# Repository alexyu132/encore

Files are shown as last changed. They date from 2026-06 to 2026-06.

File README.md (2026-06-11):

# encore
A mini CoreXY 3D printer with a 3D printed frame.

printer header imaeg

Overview video: https://www.youtube.com/watch?v=9xukniyO6fI

This is my latest CoreXY design. It's a small printer with a 120x120x120mm build volume. The total size is slightly smaller than a Voron 0, with a footprint approximately the size of a box of filament.

Unlike my older printer designs, this one uniquely uses an entirely 3D printed chassis, with no aluminum extrusions or custom CNC'd parts. This significantly reduces the total part cost, while the solid panel construction keeps things sufficiently rigid.

All of the printed parts are designed to fit on a 225mm bed, so common printers like the Ender 3, Bambu A1/P1, etc. should have no problem printing them.

For this design I focused on keeping things compact yet modular. Each major assembly (e.g. the CoreXY mechanism, the Z axis, and the outer panels, can be independently swapped out without major disassembly of the other assemblies.

| Specs |  |
| --- | --- |
| Build volume | ~120x120x120mm |
| Body dimensions (excl. Bowden parts)| 219x221x262mm|
| Extrusion| Bambu-style hotend, Bowden extruder|
| Motion| MGN9C X/Y gantry, 8mm linear rod Z + 8mm leadscrew|
| Cooling| 4015 blower (print head) + dual 7515 blower (aux)|

# BOM and assembly
View the list of printed and non-printed parts [here](documentation/BOM.md).

Assembly guide is available [here](documentation/build%20guide/build%20guide.md). Note: still WIP

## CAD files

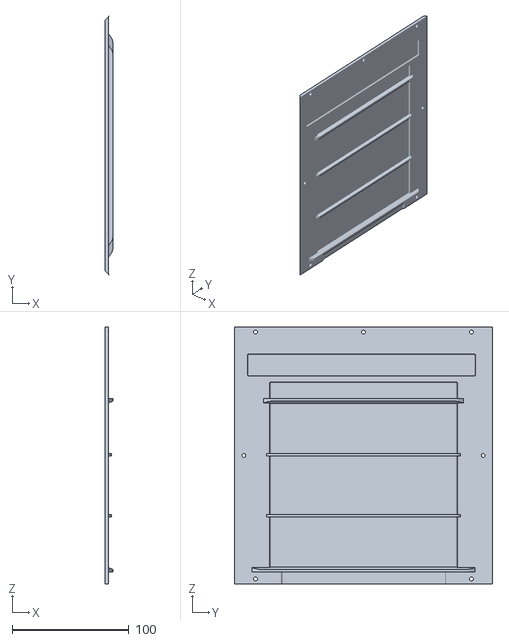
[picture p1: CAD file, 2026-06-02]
stl/enclosure/left panel unvented.stl
6.50 x 221.0 x 220.0

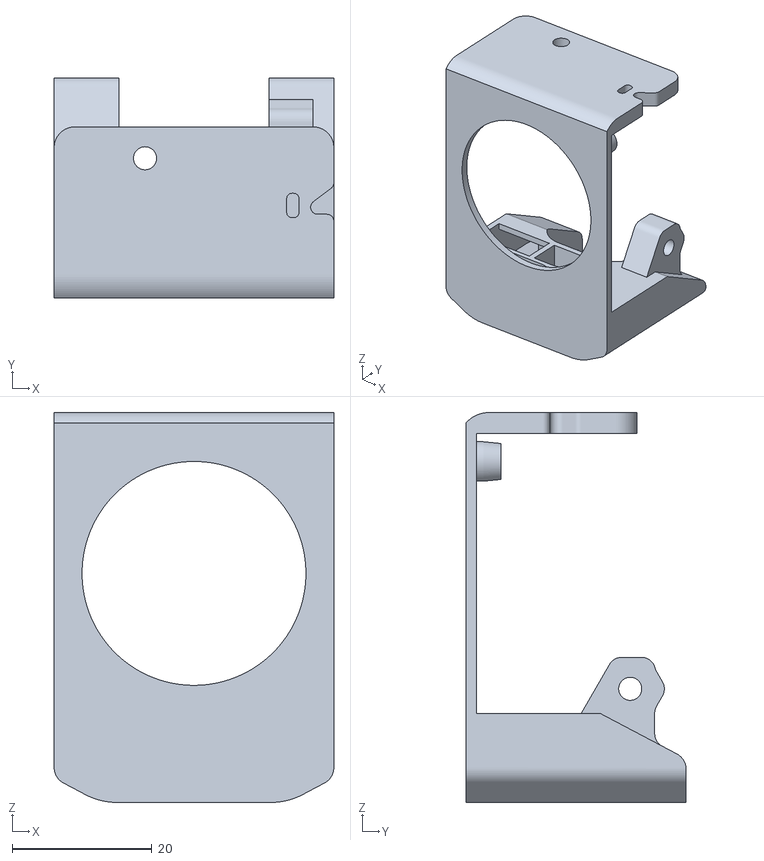
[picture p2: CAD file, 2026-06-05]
stl/gantry/print head/print fan duct.stl
40.0 x 31.5 x 55.8

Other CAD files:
stl/enclosure/right panel unvented.stl

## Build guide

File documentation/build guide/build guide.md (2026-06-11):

# Encore build guide

WIP: This is a very early version. Please flag any discrepancies via Github Issues.

## Contents

### 0. [(Pre-build) BOM](../BOM.md)

### 1. [Gantry](gantry.md)

### 2. Enclosure and Z axis

### 3. Final assembly and wiring

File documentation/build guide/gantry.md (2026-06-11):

# Encore build guide: Gantry

## 1. Front idler block pulleys

### Printed parts:
|Item|Qty|
|--|--|
|Left front idler block|1|
|Right front idler block|1|

### Non-printed parts:
|Item|Qty|
|--|--|
|M3x20mm bolt |2|
|M3 lock nut|2|
| F623 bearing |4|

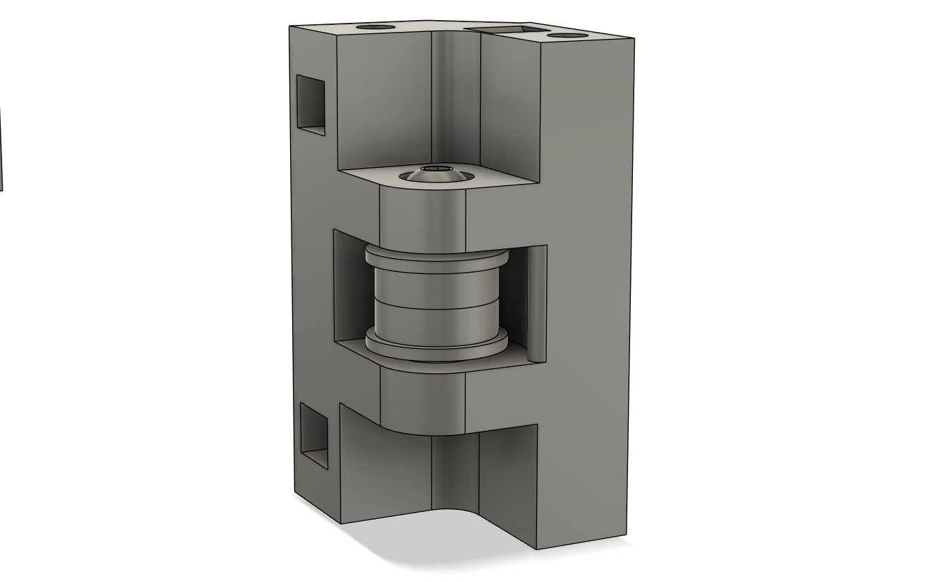
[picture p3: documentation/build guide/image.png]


For each front idler block:
- Insert 2 F623 bearings into the pulley slot. The flanges should be facing away from each other.
- Secure with an M3x20mm bolt and lock nut underneath.

## 2. Rear idler blocks and mid frame

### Printed parts:
|Item|Qty|
|--|--|
| Rear idler spacer |2|
| Rear left idler block |1|
| Rear right idler block |1|
| Rear mid frame | 1|

### Non-printed parts:
|Item|Qty|
|--|--|
|M3x30mm bolt | 4|
|M3 lock nut| 4|
|F623 bearing| 12|

For each rear idler block, install pulleys as shown in the image below. Use M3x30mm bolts inserted from the top of the part. For the double stacked pulley, the order is:
1. F623 (flange on top)
2. F623 (flange on bottom)
3. Rear idler spacer
4. F623 (flange on top)
5. F623 (flange on bottom)

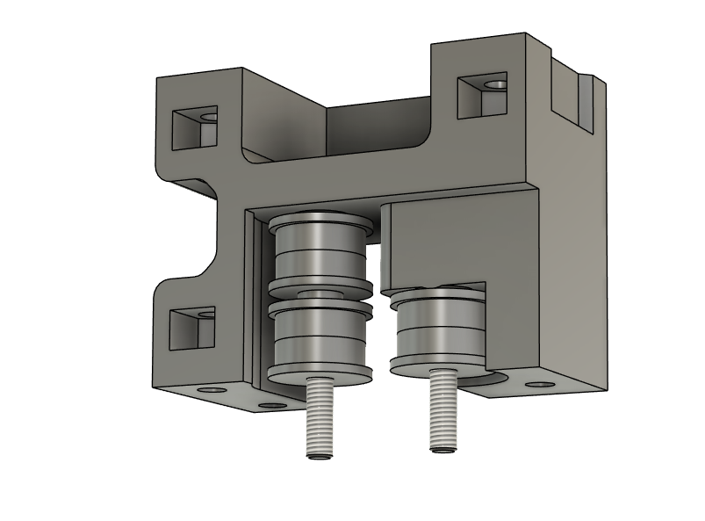
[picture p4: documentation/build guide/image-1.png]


Install the rear midframe underneath and secure the M3x30mm bolts via 2 M3 lock nuts.
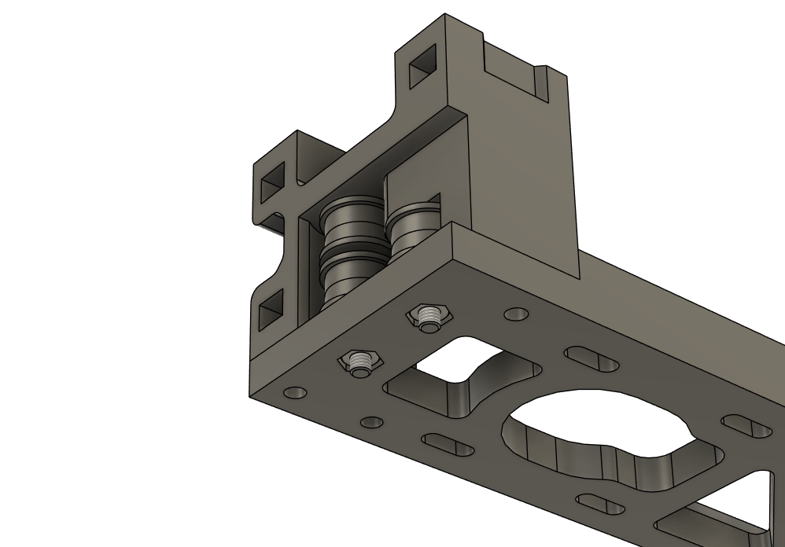
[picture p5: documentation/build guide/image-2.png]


Repeat the same steps for the other side; the resulting assembly should look like the following:
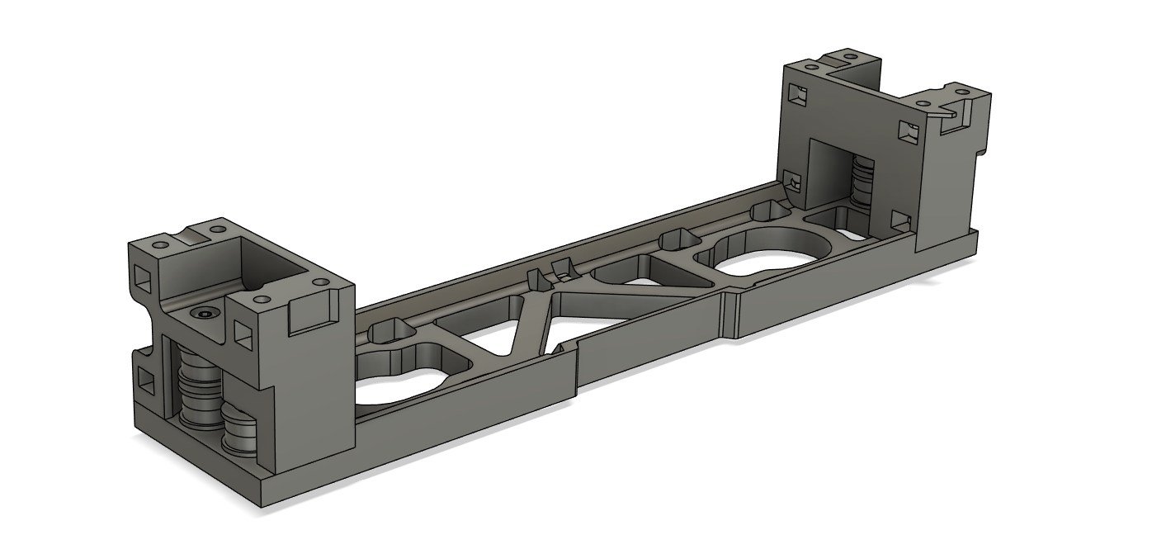
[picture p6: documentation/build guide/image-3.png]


## 3. Upper frame attachment

### Printed parts:
|Item|Qty|
|--|--|
| Top chassis |1|

### Non-printed parts:
|Item|Qty|
|--|--|
|M3x12mm bolt | 12|
|M3 lock nut| 12|

Insert 4 lock nuts into the top slots of the rear left and right idler blocks
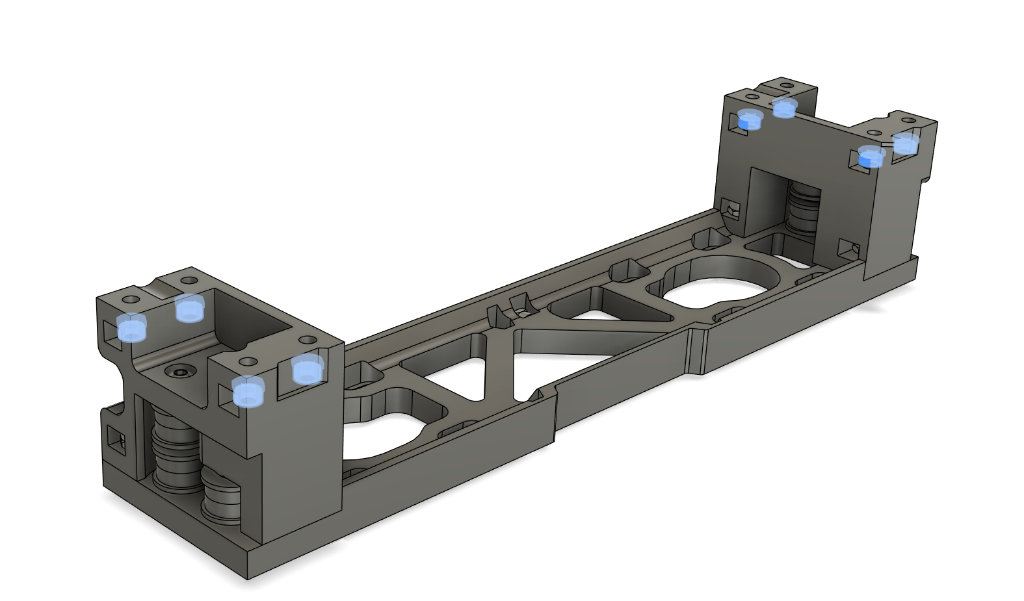
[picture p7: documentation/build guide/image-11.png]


Attach the top chassis to the rear idler assembly using 8 M3x12mm bolts:
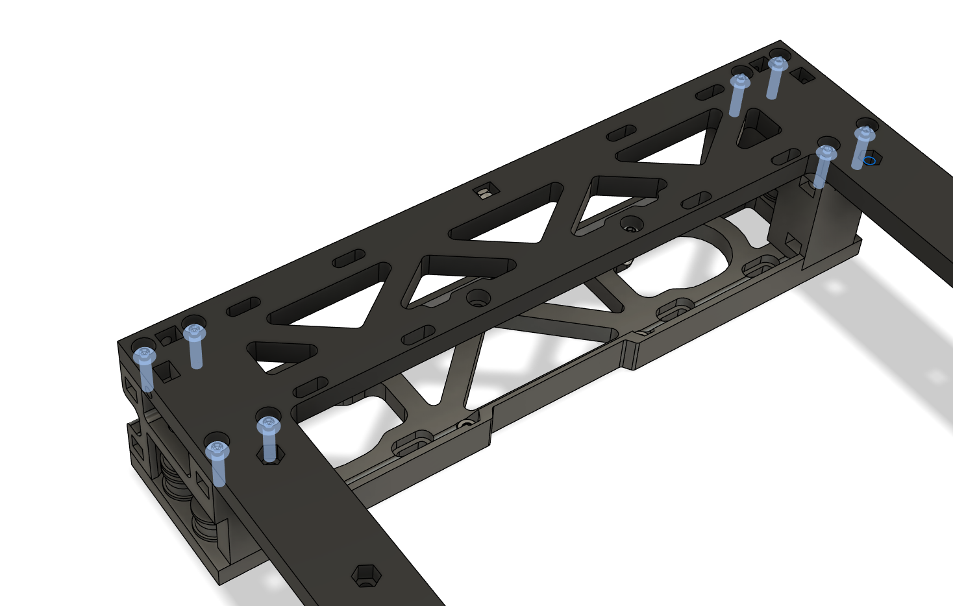
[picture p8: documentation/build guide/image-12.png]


Attach the left/right front idler blocks to the top chassis using 4 M3x12mm bolts and 4 lock nuts:
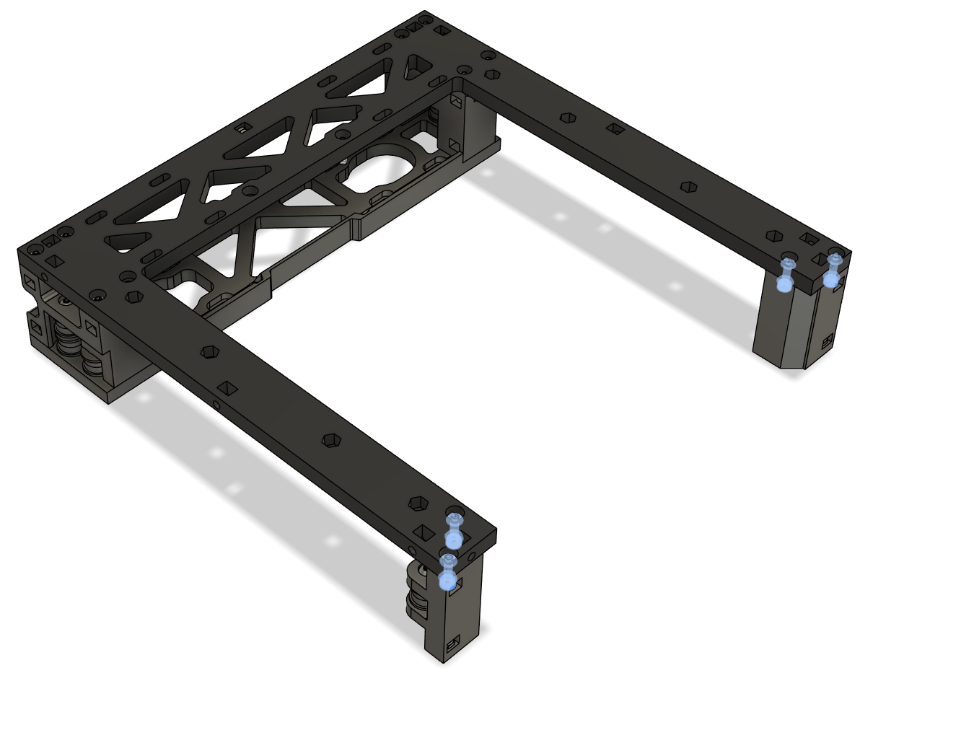
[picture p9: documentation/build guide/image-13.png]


## 4. Linear rail installation

### Non-printed parts:
|Item|Qty|
|--|--|
| 150mm MGN9 rail with MGN9C carriage |2|
|M3x10mm bolt | 8|
|M3 lock nut| 8|

Note: The linear rails should be properly prepped and greased before assembly. See this guide for the necessary steps: https://docs.ldomotors.com/guides/rail_grease_guide

Install the right side linear rail using 4 M3x10mm bolts and 4 lock nuts. Note: use the triangular tabs on the front/rear right idler blocks to align the rail.
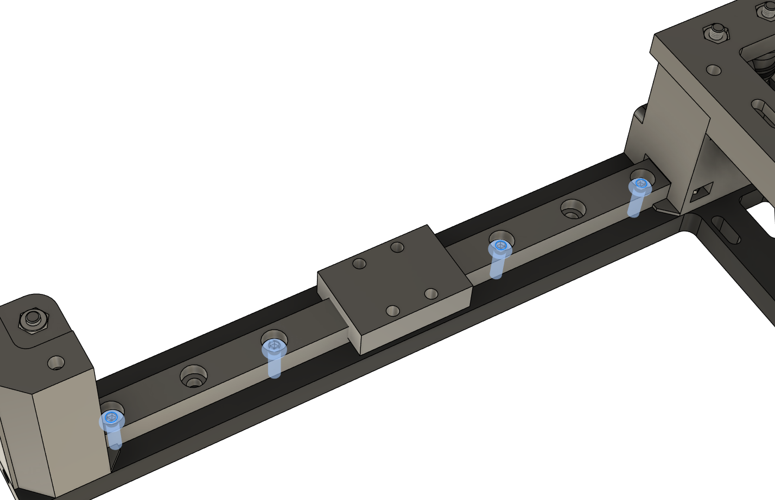
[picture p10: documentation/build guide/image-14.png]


Install the left side linear rail in the same fashion. NOTE: Leave the bolts loose for now; final tightening will be done when the X gantry is installed.
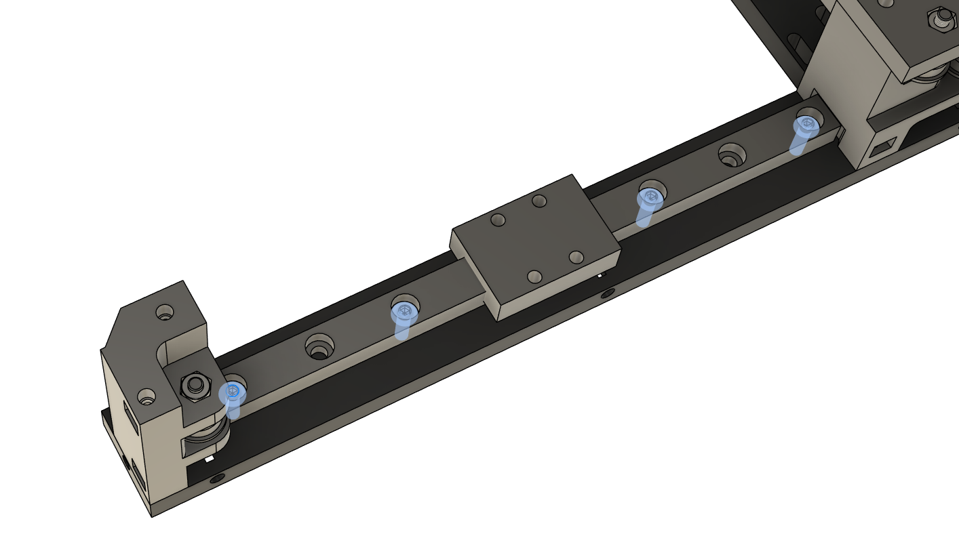
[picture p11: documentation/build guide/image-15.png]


## 5. X gantry assembly
### Printed parts:
|Item|Qty|
|--|--|
| Gantry body |1|
| Gantry left end |1|
| Gantry right end |1|

### Non-printed parts:
|Item|Qty|
|--|--|
|M3x25mm bolt | 4|
|M3x12mm bolt | 4|
|M3x30mm bolt |4|
|M3 lock nut| 8|
| 150mm MGN9 rail with MGN9C carriage | 1 |

Install 2 M3x25mm bolts and F623 bearings as shown onto the gantry left end:

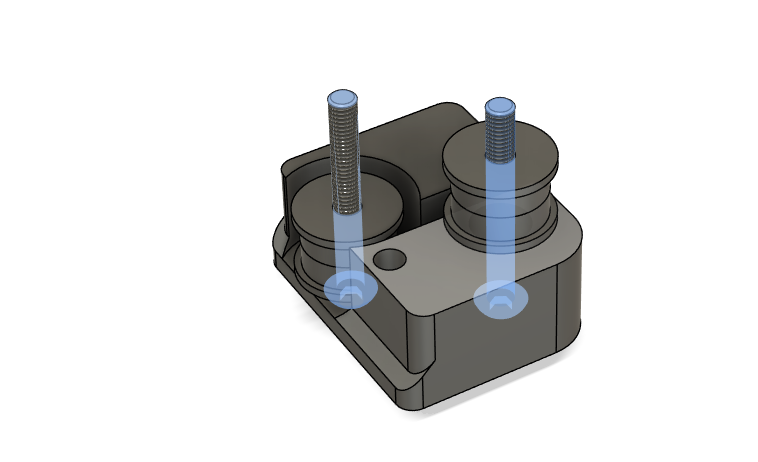
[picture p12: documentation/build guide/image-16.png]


Secure the left end onto the gantry body using 2 lock nuts:
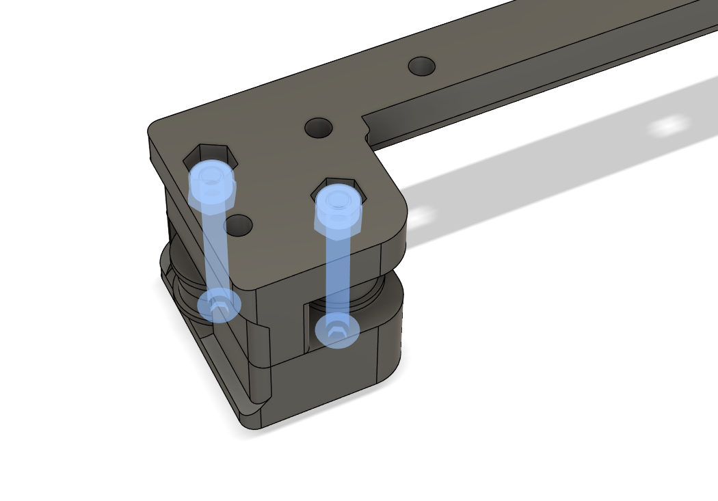
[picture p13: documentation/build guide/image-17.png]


Repeat the same steps for the right end:
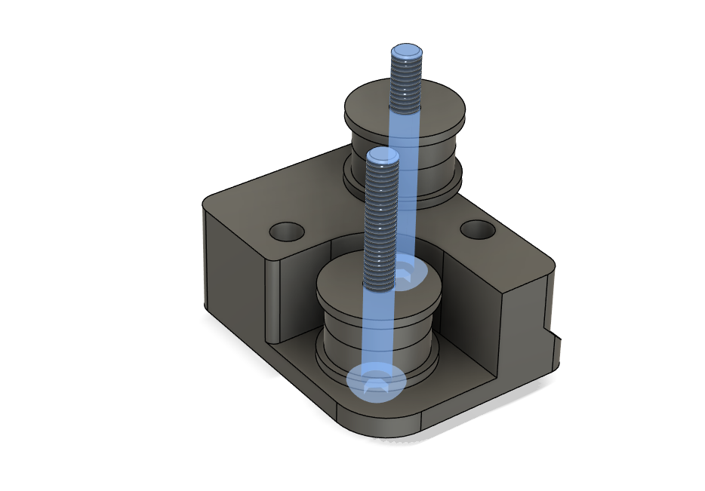
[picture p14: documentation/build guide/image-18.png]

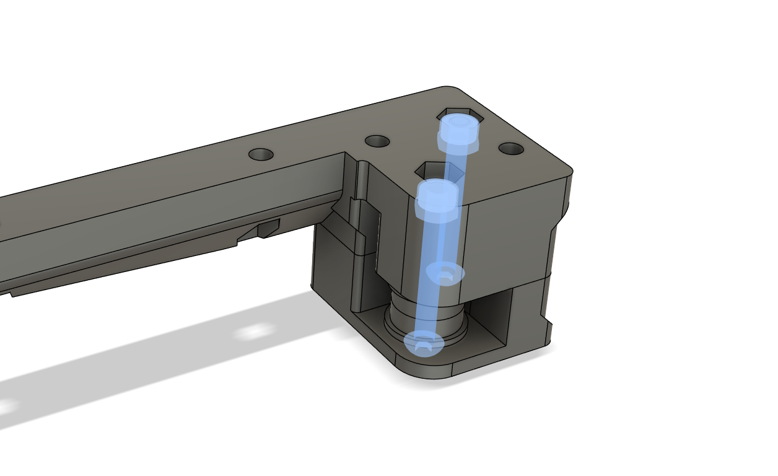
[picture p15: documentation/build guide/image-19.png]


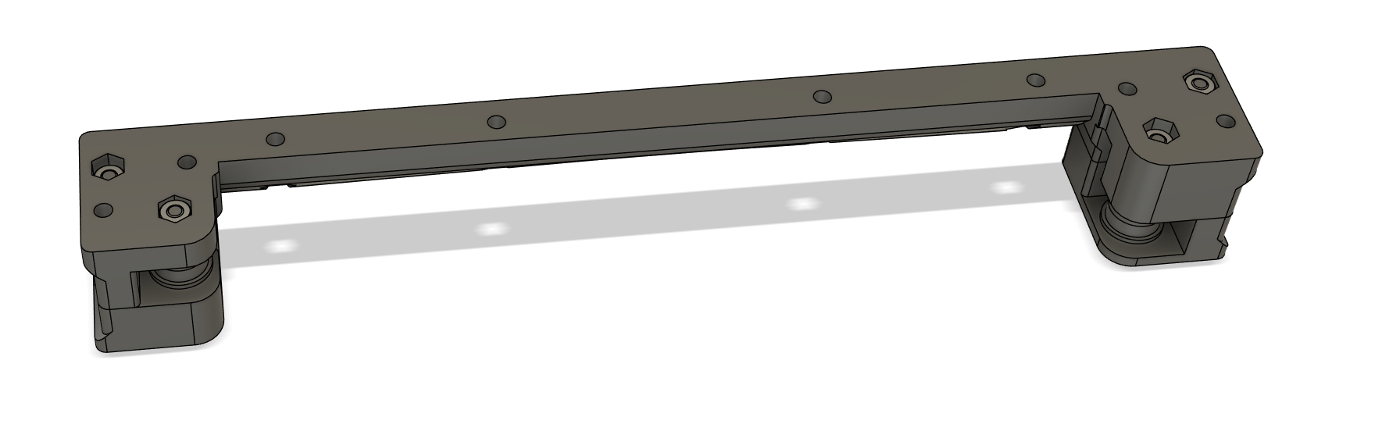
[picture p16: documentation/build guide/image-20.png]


Use 4 M3x12mm bolts and 4 lock nuts to secure the 150mm MGN9 rail to the gantry body:
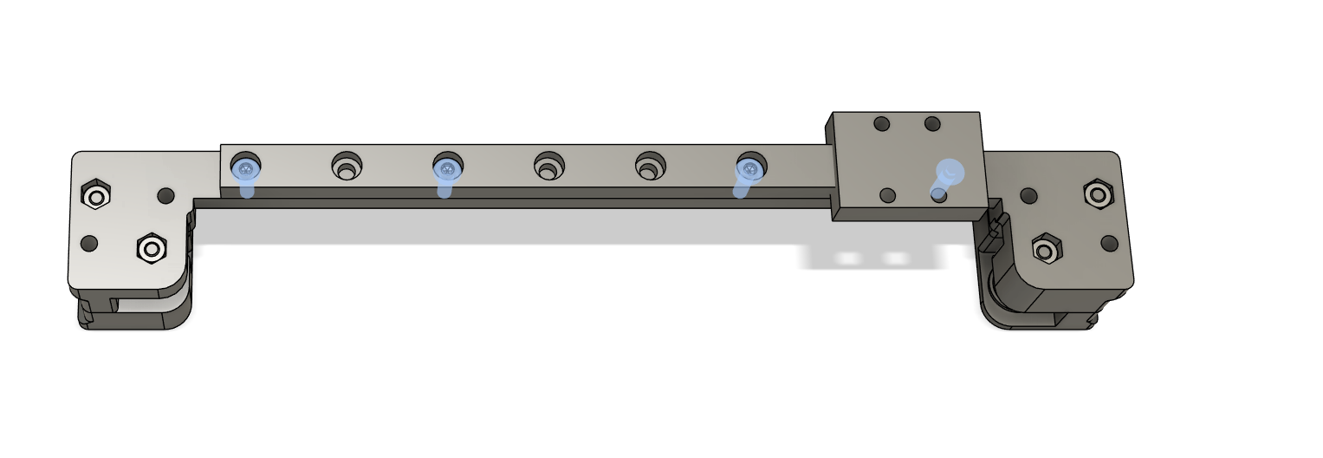
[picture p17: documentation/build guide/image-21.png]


Use 4 M3x30mm bolts to secure the X gantry to the Y rails:
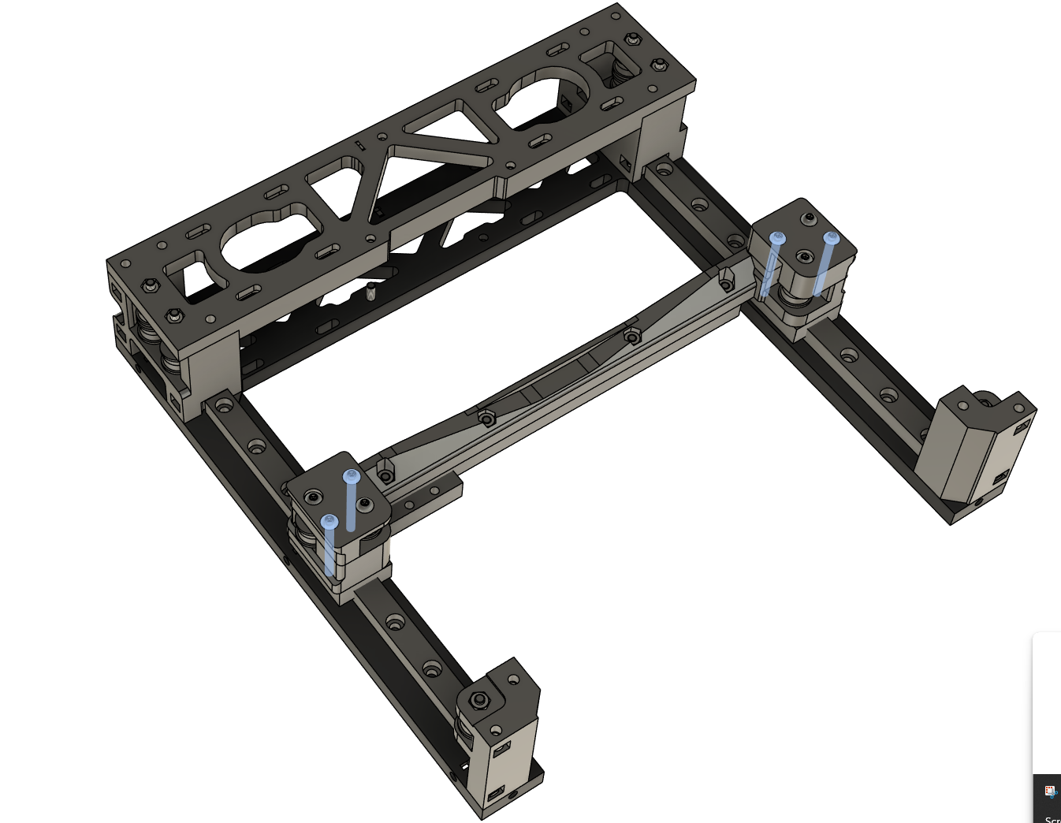
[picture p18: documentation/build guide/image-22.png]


After the X gantry is installed, run it back and forth to each end, and tighten the bolts on the left Y rail. Make sure movement is smooth throughout the entire Y travel.
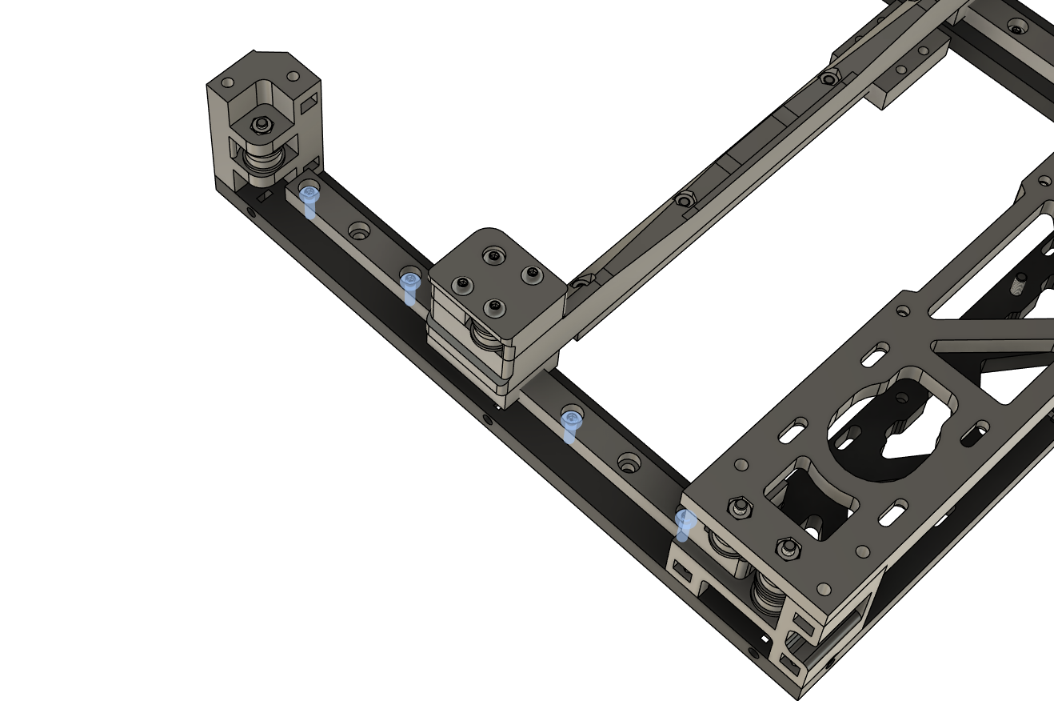
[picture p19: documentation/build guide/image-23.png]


## 6. Y endstop installation

### Printed parts:
|Item|Qty|
|--|--|
| Y endstop mount |1|

### Non-printed parts:
|Item|Qty|
|--|--|
|M3x8mm bolt | 2|
|M3x10mm bolt |2|
|M3 lock nut| 4|
| PCB endstop | 1 |

Install a PCB endstop onto the Y endstop mount using 2 M3x8mm bolts and 2 lock nuts:
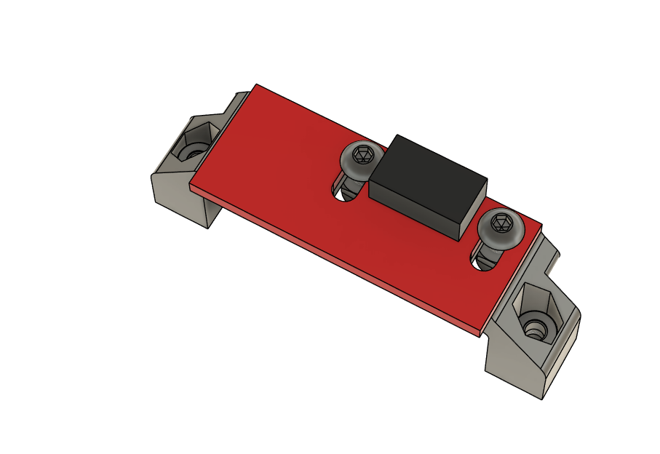
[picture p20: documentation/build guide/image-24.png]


Install the Y endstop onto the top chassis using 2 M3x10mm bolts and 2 lock nuts:
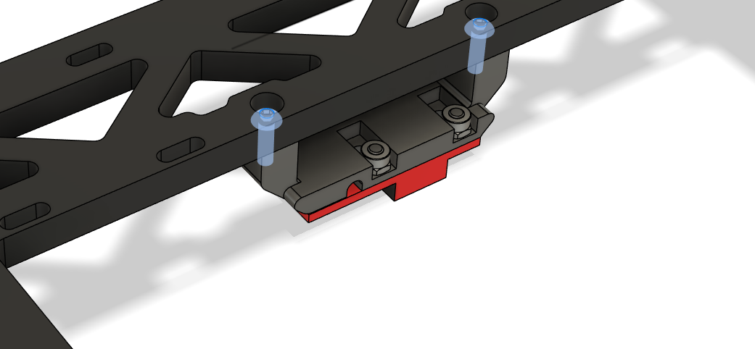
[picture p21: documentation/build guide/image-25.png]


Full assembly:
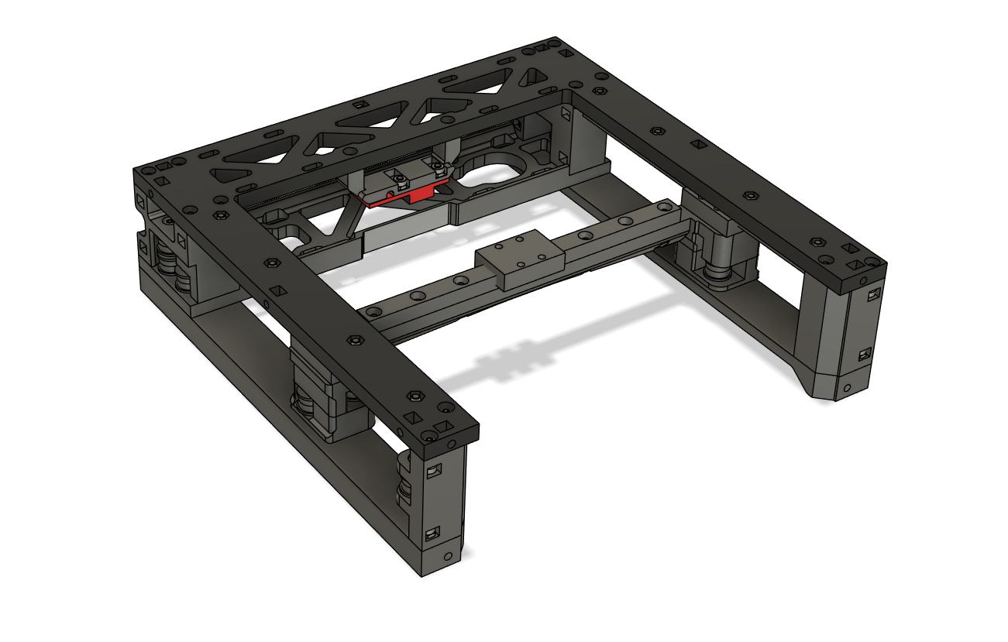
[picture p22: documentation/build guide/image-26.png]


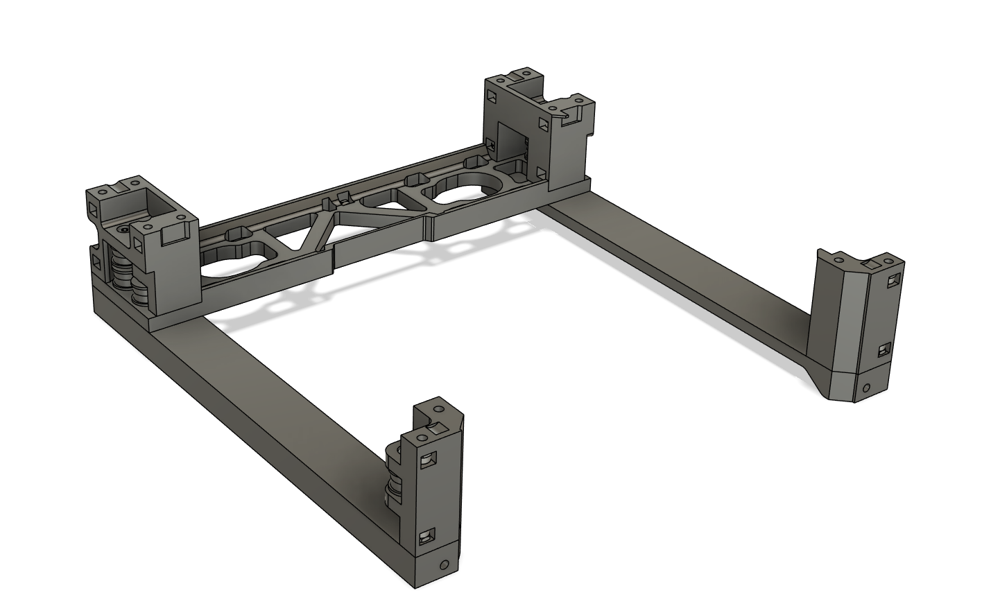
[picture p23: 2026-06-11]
documentation/build guide/image-9.png

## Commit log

2026-06-02 add unvented panels
    [left panel unvented.stl, right panel unvented.stl]
2026-06-05 Add zip tie mounting hole to fan duct, add missing screws to model
    [print fan duct.stl]
2026-06-11 Build guide: gantry
2026-06-18 Add belt tensioning guide
2026-06-18 Gantry instructions: print head
2026-06-18 Z axis instructions
2026-08-29 Enclosure instructions
